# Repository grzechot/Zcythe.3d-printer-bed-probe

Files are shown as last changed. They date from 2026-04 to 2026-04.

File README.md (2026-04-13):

Shield: [][cc-by-nc-sa]

This work is licensed under a
[Creative Commons Attribution-NonCommercial-ShareAlike 4.0 International License][cc-by-nc-sa].

[][cc-by-nc-sa]

[cc-by-nc-sa]: http://creativecommons.org/licenses/by-nc-sa/4.0/
[cc-by-nc-sa-image]: https://licensebuttons.net/l/by-nc-sa/4.0/88x31.png
[cc-by-nc-sa-shield]: https://img.shields.io/badge/License-CC%20BY--NC--SA%204.0-lightgrey.svg

# Zcythe - 3d printer bed probe. 

- Accuracy - 0.003mm
- Cost ~2€
- Weight - 12grams
- Printable

Here you ca see how it works:

https://www.youtube.com/watch?v=oTdeM-AWUHY

## Parts:
- printable: Flag6.stl and ZSuport6.stl. Recommended material - ABS. PETG might warp close to heat sources like extruder motor.
- optosensor 5V - something like that: https://www.amazon.de/-/en/Endstop-OptoEndstop-Optical-Mendel-Printers/dp/B08S7FQCJ8
- 3x7x3 bearing 2pcs. Soak before use in grease. I use hot paraffin bath.
- 5x5mm brass heat insert with collar.
- 3mm steel ball 
- 0.5x5mm magnet 2pcs. It can sourced from OCB cigarette paper package.
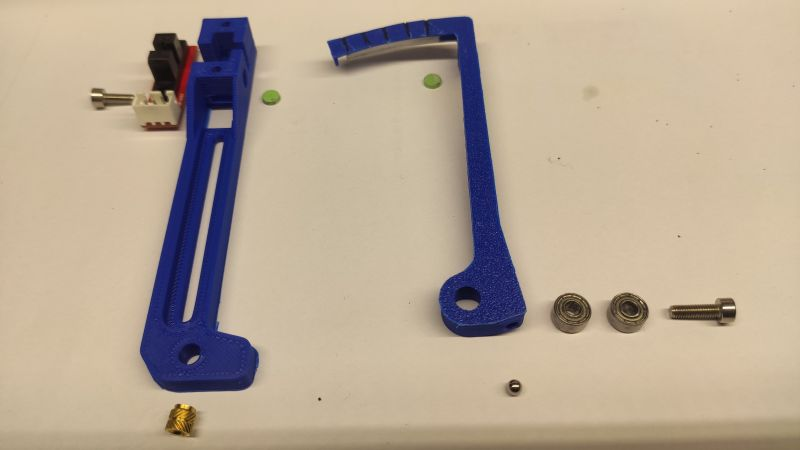
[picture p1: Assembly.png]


I`ve came with that idea about year 2013. Here you see prototype, working as precise ZEndStop, fitted in my old 3d printer:

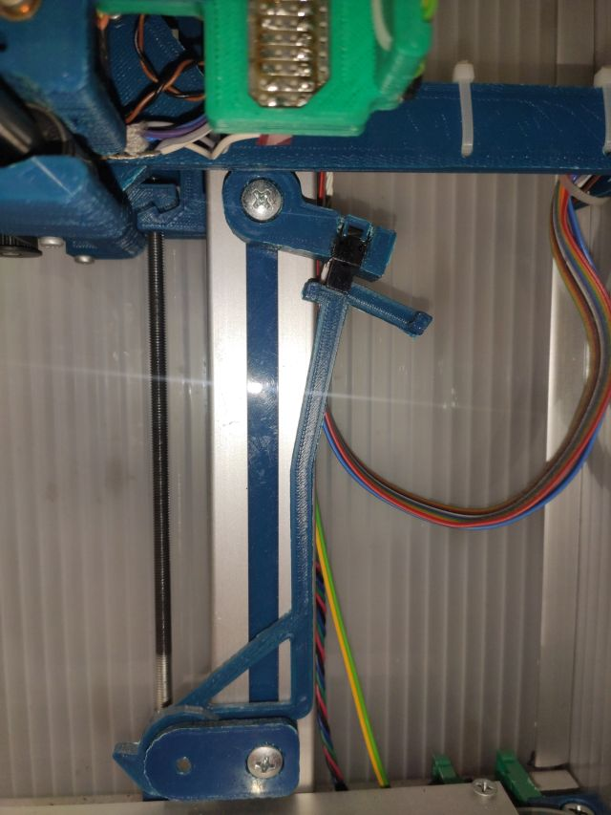
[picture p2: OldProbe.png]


After 13 years it's still working fine with no issues. But mounted to the frame can't be used to do mesh bed probing. So I had to redesign a little. The red one is printed in PETG, and it started to warp from extruder motor heat. ABS recommended. 

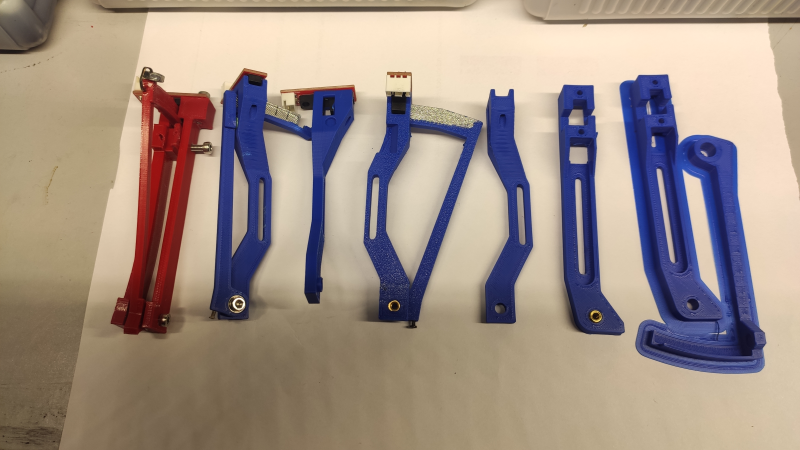
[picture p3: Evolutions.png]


The principle is simple. Because the accuracy of OptoEndStop is around 0.05 to 0.1mm. It's far not enough to work as ZEndStop. But if we use a leverage, we can enhance accuracy by leverage ratio. I use ratio about 1:12, whitch is enough to measure with 0.003mm accuracy. If we extend the lenght of the scythe, the accuracy might be better. The practical limit is a height from a nozzle to a top of an extruder motor.
After developing several versions, I came to the point of "good enough, ready to publish". And here it is:

## Assembly instructions:

Press both bearings into the slot in the ZFlag. Leave no space between two of them.

Heat press the ball, close holes between the ball and plastic part. Make sure tha ball will not fall out.

Heat press magnets to both parts, similar to brass insert. Mind the polarity!

The socket of the EndStop have to be desoldered, and soldered on the same side as OptoSensor.

Prepare ZSupport by removing printed supports. Press fit OptoSensor. One M3x6mm bolt is enough to secure. When preparing cables, mind polarity!

Paint with black or silver surfaces on the photo. Cut 0.5mm of the edge.

Heat press the brass insert. The narrow part stays outside. 

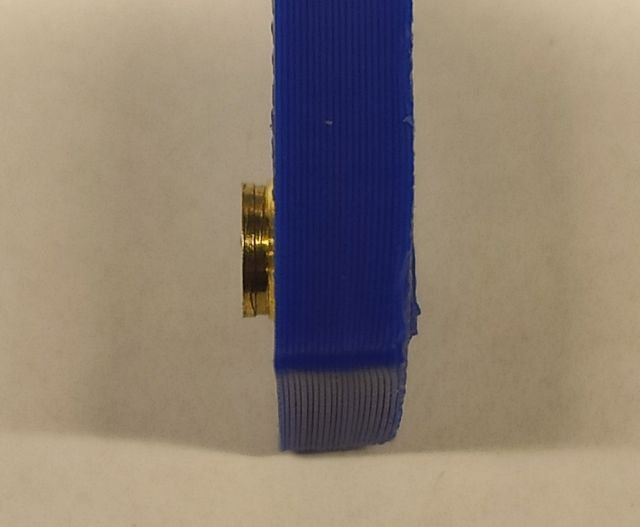
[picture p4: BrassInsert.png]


Screw with M3x10mm bolt ZFlag to the ZSupport. Check bearings work. It should rotate without any resistance. Check spaces between painted surfaces and OptoSensor. It can not touch each other. Adjust the mount of the brass insert eventually.

Test magnets. The arm should be magnetically atrracted from about half of its travel, and locked in closed state. Orient Zcythe vertically, push ZFlag gently, it should rotate to open state. Repeat many times :) Play with it as it's a fidget, because that assembly must withstand tens thounsands off cycles. 

The most difficult part: find the place at your extruder, where a mount is possible. Create support for your extruder to the Zcythe. Soon I will post mounts for Voron and RatRig.

## Configure

Connect, configure (simple endstop, Z offset about 1mm, normally open). RRF gcode: M558 P5 C"zstop" H1.2:0.4 F150:90 T30000 A5 S0.003

## Test
Rotate ZFlag to open position. LED must be on, and controller must report open state of the OptoSensor.
After turning ZFlag less then 1mm on the upper side, the led must turn off.
Repeat many times.

## Position and launch

The closed probe (ZFlag deretracted, magnetically locked) shoul be about 1mm above nozzle tip. Rotate ZFlag to open state. The ball should be about 1mm below the nozzle tip. Secure with two bolts. Don't overtighten.
Calibrate traditionally using thin paper.

While probing, XY accelerations must be around 2000mm/s^2, because it may trigger the probe. But even with that limitation the probe can measure 6x6 grid in less than 3 minutes! Anyway, most aluminium plated beds change shape and height while heating, while stabilizing temperature, and even midprint. You can measure this with my probe. Have fun!

Here is 21x21 grid of my imperfect bed. RRF configuration: M588 A5 S0.003. And day after day it looks similar, whitch means the probe is working great!.



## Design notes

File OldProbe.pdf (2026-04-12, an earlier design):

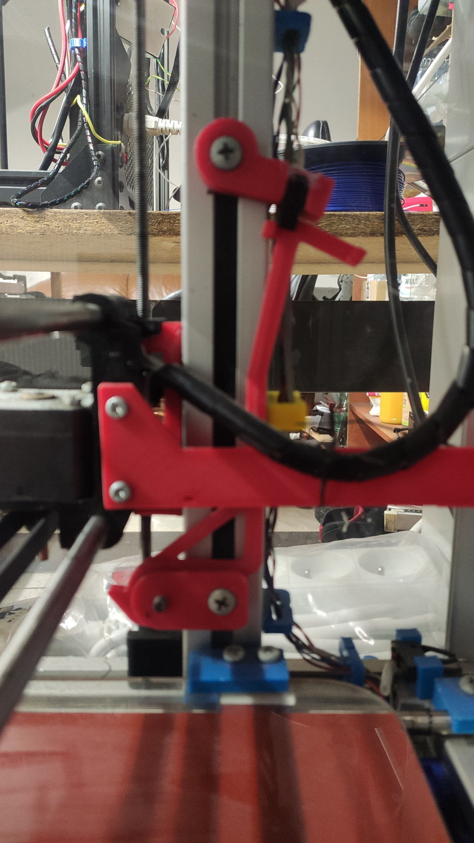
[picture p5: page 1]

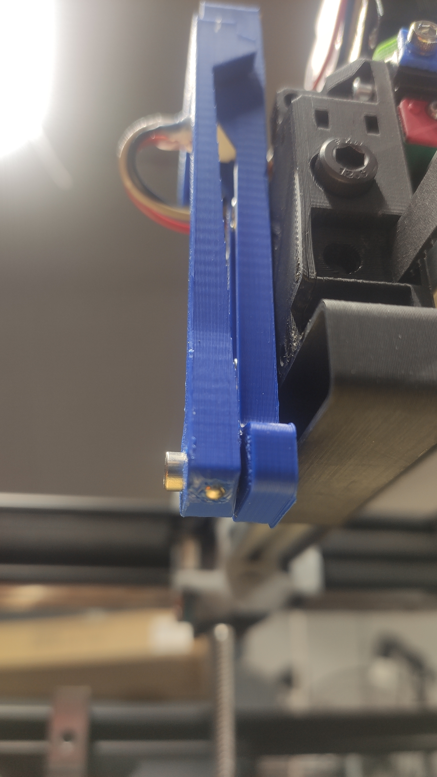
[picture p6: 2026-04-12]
Ball position.jpg

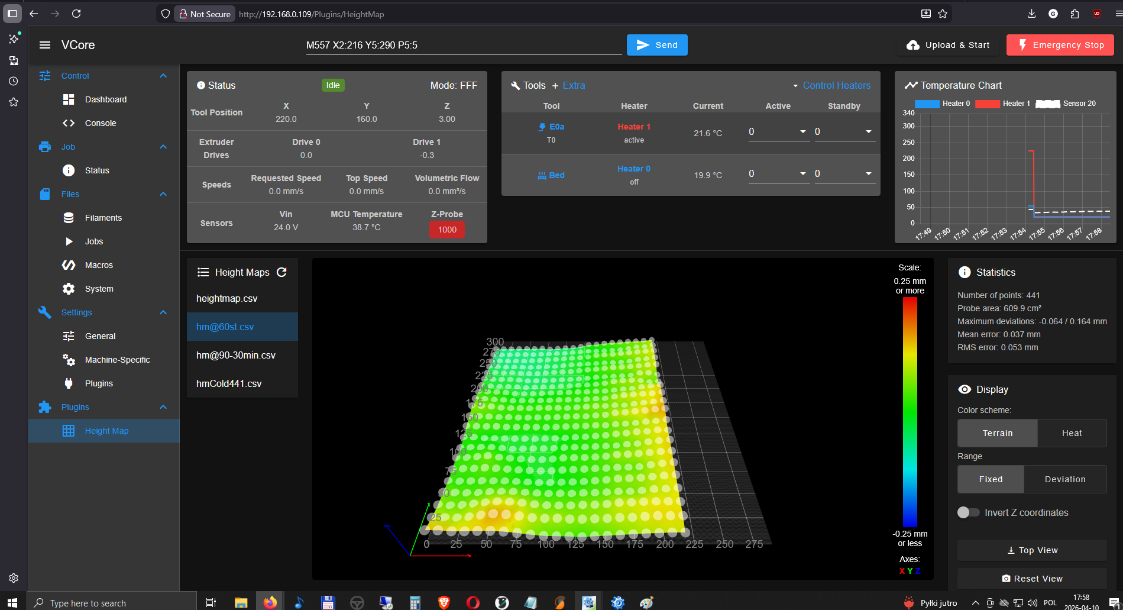
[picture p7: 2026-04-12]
Zcithe441.png

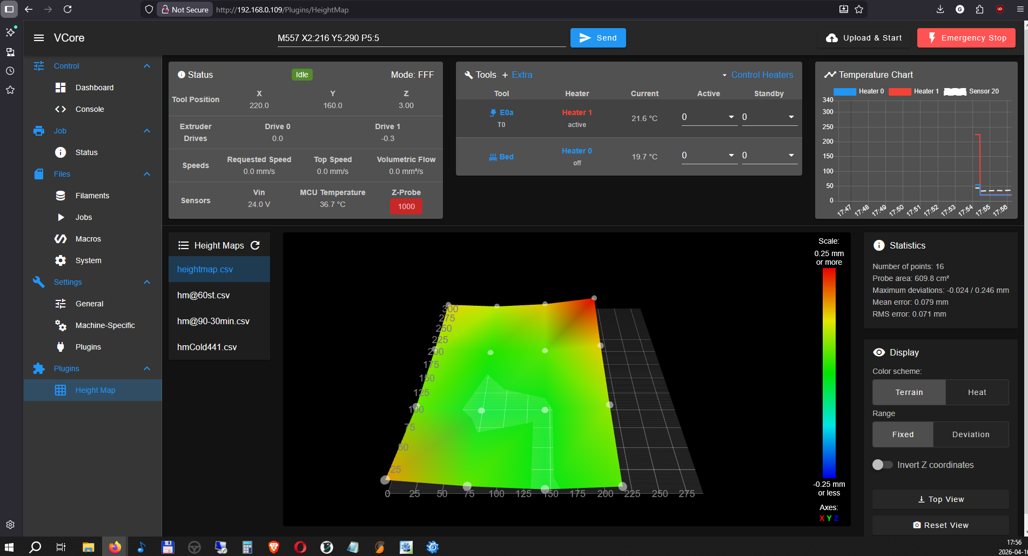
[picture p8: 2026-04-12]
Zsithe441Former.png

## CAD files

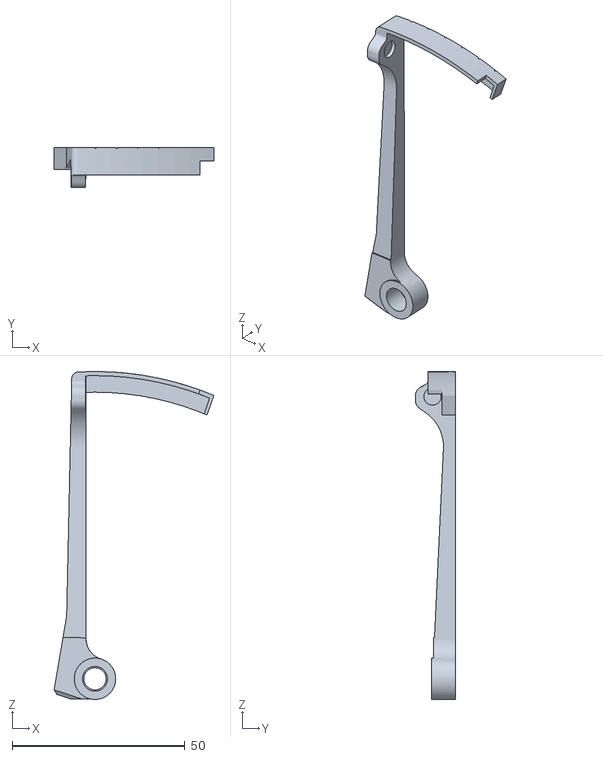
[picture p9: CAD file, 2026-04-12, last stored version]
Flag3.stl
46.3 x 11.7 x 95.0

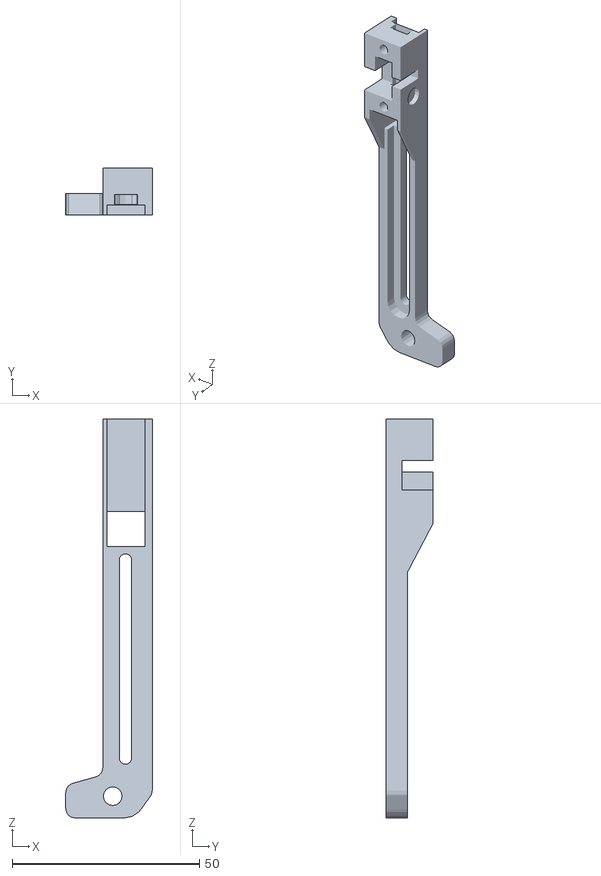
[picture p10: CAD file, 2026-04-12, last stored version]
ZscitheSupport.stl
23.1 x 12.5 x 106.5

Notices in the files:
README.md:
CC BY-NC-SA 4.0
